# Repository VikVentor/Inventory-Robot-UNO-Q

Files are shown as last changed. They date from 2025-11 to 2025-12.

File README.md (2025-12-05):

# Smart Inventory Robot (Edge Impulse + UNO Q)
## Click to watch the video!
<a href="https://youtu.be/sMjTuYHo2wQ">
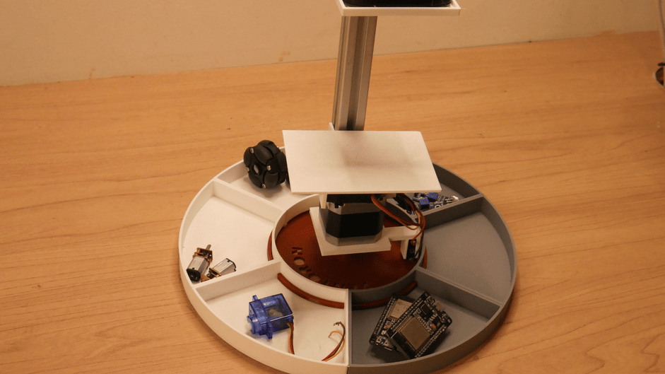
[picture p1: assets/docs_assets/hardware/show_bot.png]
  
</a>
<br>

## Introduction

This project walks you through building your own **Inventory Robot** that can automatically identify, organize, and track the components you use in your workspace. After finishing a prototype, placing every part back in the right spot can become time-consuming and difficult. This robot solves that by intelligently sorting and maintaining a clear inventory of your items.

Whether you are a beginner or a hobbyist, this guide makes it simple to understand how the robot works, how to train your machine learning model on **Edge Impulse**, and how to integrate everything with the **Arduino UNO Q**.

---

## Table of Contents

1. [Identified Problem](#1-identified-problem)  
2. [Proposed System (Solution)](#2-proposed-system-solution)  
3. [What You Will Learn](#3-what-you-will-learn)
4. [System Overview](#4-system-overview)
   - **4.1 [Hardware](#41-hardware)**  
   - **4.2 [Software](#42-software)**  
5. [System Design & Development](#5-system-design--development)
   - **5.1 [System/Hardware Design](#51-system--hardware-design)**  
   - **5.2 [Dataset Preparation](#52-dataset-preparation)**  
   - **5.3 [Training of the AI Model](#53-training-the-ai-model)**  
   - **5.4 [Optimization of AI Model](#54-optimization-of-ai-model)**  
   - **5.5 [Integration of model with UNO Q](#55-integration-of-model-with-uno-q)**  
   - **5.6 [Arduino Appilcation Development](#56-Arduino-Appilcation-Development)**  

6. [System Testing](#6-system-testing)  
7. [Summary of Challenges](#7-summary-of-challenges)  
8. [Advantages of Arduino UNO Q](#8-advantages-of-arduino-uno-q)
9. [Conclusion](#9-conclusion)

---

## 1. Identified Problem

When working on electronics projects, components often get scattered all over the workspace. After finishing your work, identifying and sorting them back into their correct locations becomes tiring. This leads to misplaced parts, wasted time searching, and reduced productivity.
#### If you are a hobbyist, your desk on an average day might look like this.
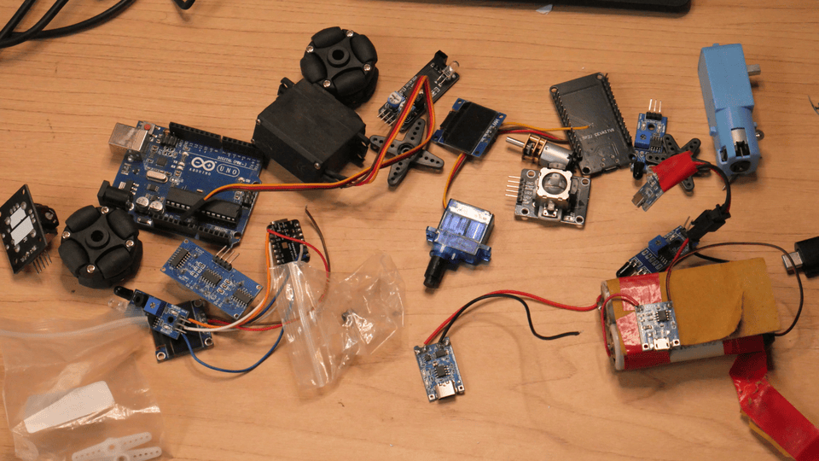
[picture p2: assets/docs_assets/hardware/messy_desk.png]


Manual sorting is repetitive and error-prone. As your component collection grows, keeping track of everything becomes even harder.

This project focuses on creating an automated system that can:

* Quickly identify items
* Count them accurately
* Sort and position them correctly
* Maintain a consistent, updated inventory

With the Arduino UNO Q and Edge Impulse, this project eliminates the repetitive steps and builds a smart, reliable solution.

---

## 2. Proposed System (Solution)

### Smart Inventory Robot with Arduino UNO Q
### After finishing a prototype, placing every part back in the right spot can become time-consuming and difficult. This robot solves that by intelligently sorting and maintaining a clear inventory of your items.

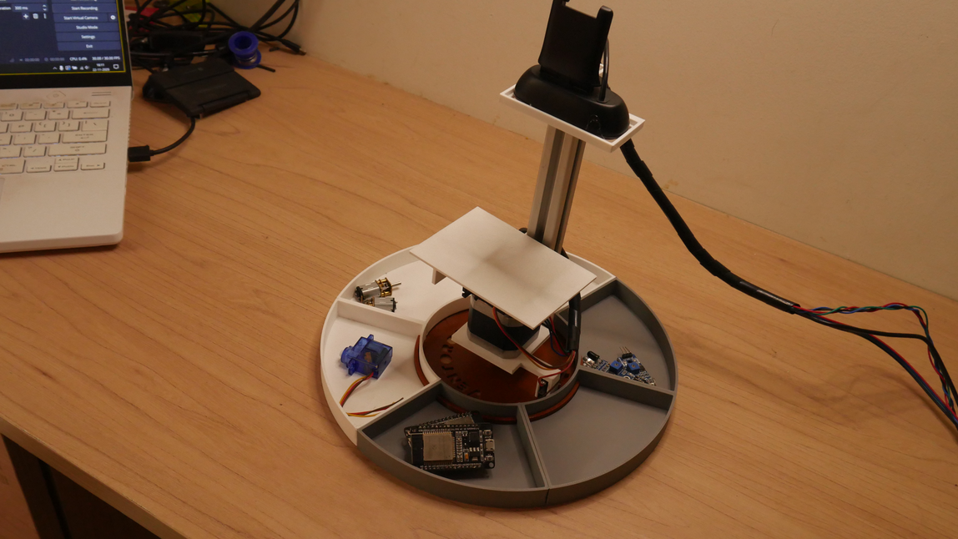
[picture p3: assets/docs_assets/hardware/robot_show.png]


### Features:
1. Automatic sorting of components into container
2. Updates total quantity of object when placed
3. You can pick any component and show it once to the camera and the total quantity will be updated.
4. find the container of a particular component

### Here's the WEB UI where you can see the detections in real time and use the find and pick feature.
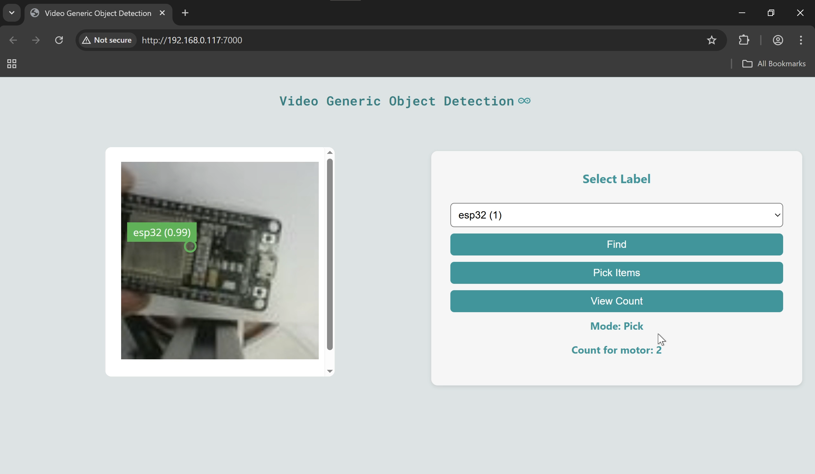
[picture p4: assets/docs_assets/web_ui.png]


---

## 3. What You Will Learn

Here are the key concepts you’ll learn while building this project:

1. How to train an ML model in **Edge Impulse**, optimize it, and integrate it into your **Arduino UNO Q** application.
2. How to utilize the UNO Q’s core ability—seamless software-to-hardware communication through the **Bridge API**.
3. How to adapt this software workflow to your own hardware setup.

**To make the process easier, I have also built the entire hardware and included all the STL files you need.**
The robot has a simple design focused on showcasing how the Arduino UNO Q and Edge Impulse can work together for smart inventory management.

---

## 4. System Overview
The Smart Inventory Robot combines autonomous navigation, vision-based item recognition, and automated sorting to manage components efficiently. The system uses a camera and machine learning model trained on Edge Impulse to classify items in real time, while the Arduino UNO Q controls the robot’s movement and mechanical sorting mechanism. Detected components are logged and organized automatically, maintaining an up-to-date inventory without manual effort. This integrated setup ensures accurate tracking, reduces human error, and streamlines workspace organization.

### 4.1 Hardware:
- An actuator (Stepper motor in this case) to navigate to the location of the respectrive object container.
- A Servo motor that drops the items once it reaches the destination container.
- A camera with adjusted focus
- Assembly of hardware (Using my design or yours)
  
### 4.2 Software:
- Arduino App Lab: to run the App that consists of your pyhton detection code and your arduino sketch to control the actuator.
- Edge Impulse Studio: This is where you will train and optimise your Edge AI model.
- Integrate your Edge AI model with your Arduino App

### Finally Software to Hardware communication is achieved using the Bridge API of UNO Q. (It will be clear in the next steps).

## 5. System Design & Development

## 5.1 System / Hardware Design

### Concept
This hardware setup is built as a **Proof of Concept** to demonstrate the Edge AI application.  
A **radial motion mechanism** is used for its simplicity, stability, and ease of construction.

### CAD / STL Files  
All CAD/STL files are provided.

### Hardware Used
- Arduino Uno Q  
- Logitech C270
- Arduino CNC Shield  
- NEMA 17 Stepper Motor (with long cable)
- A4988 Stepper Motor Driver
- Limit Switch  
- 20×20 Aluminum Extrusion (≥15 cm)  
- MG995 Servo Motor  
- 1 m wires (×4)  
- T-nuts for 20×20 extrusion  
- M3 screws

### Circuit Diagram
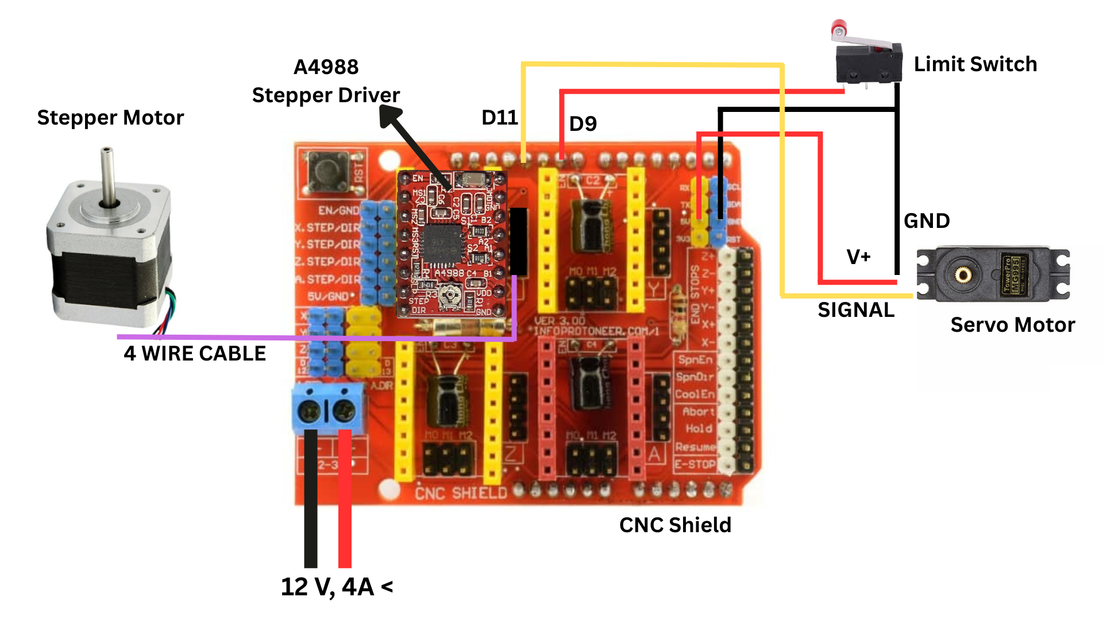
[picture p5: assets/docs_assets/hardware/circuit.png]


<br>
The long wires are for the servo motor and limit switch<br>
Among the 4 wires, 1 common wire is for the GND.
---

### a. Construct the Base  
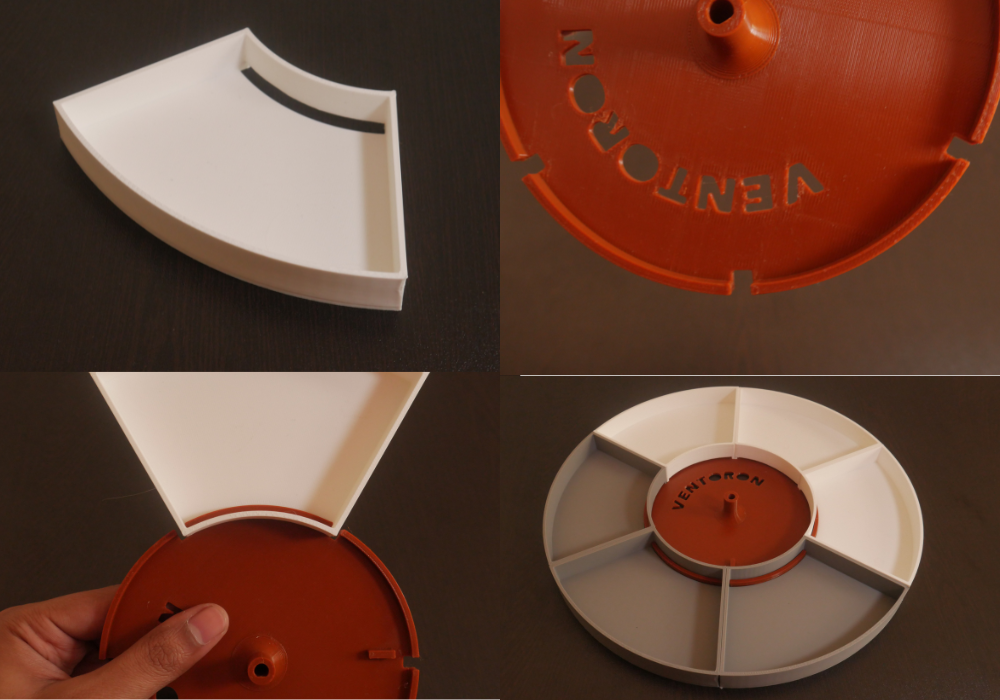
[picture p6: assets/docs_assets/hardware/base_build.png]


---

### b. Mount the Stepper Motor
Attach the aluminum extrusion to the base using a T-nut, as shown.  
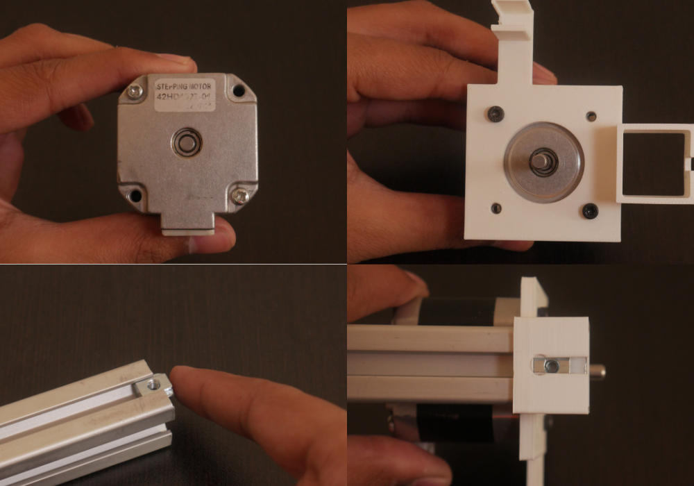
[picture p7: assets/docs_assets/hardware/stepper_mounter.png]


---

### c. Install the Limit Switch  
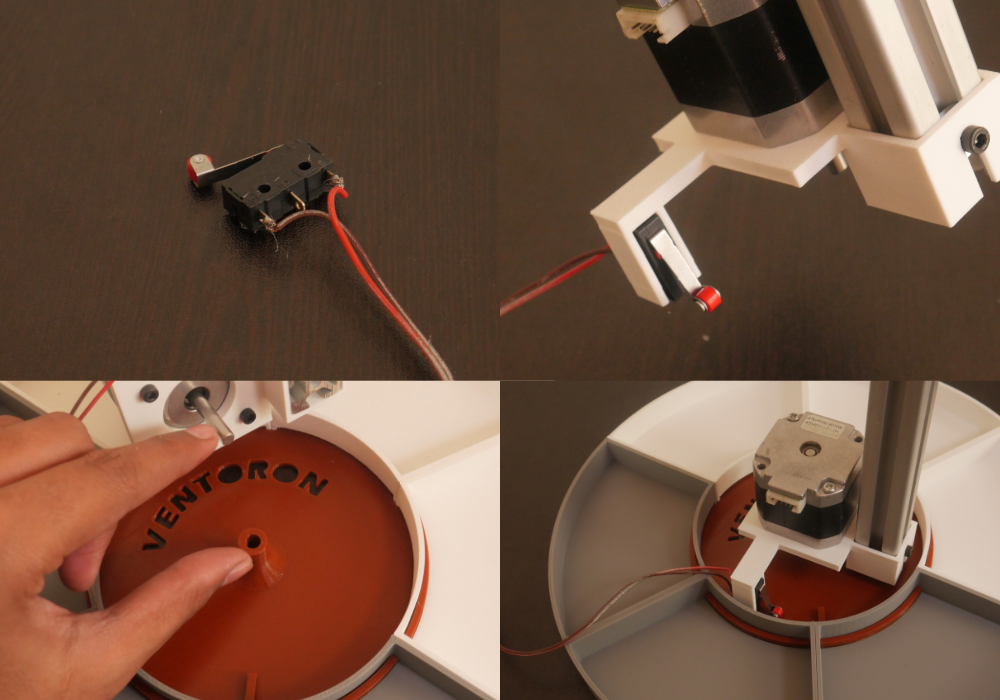
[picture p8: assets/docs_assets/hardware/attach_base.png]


---

### d. Mount the Servo and Detection Platform  
Secure the servo to the platform using the screw provided with the servo.  
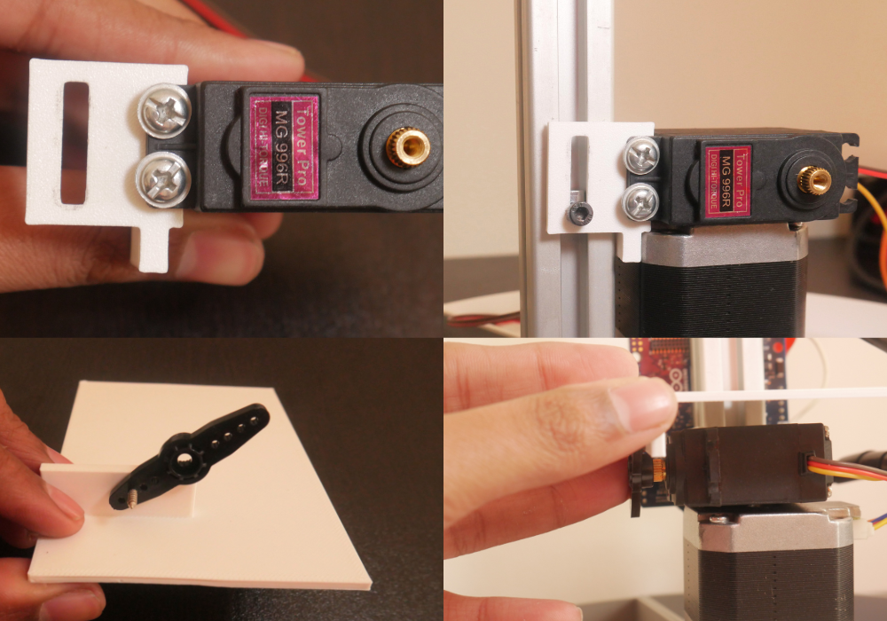
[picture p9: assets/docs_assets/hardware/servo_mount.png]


### e. Cover wires with wire sleeve
After covering the wires, you can push the sleeve into the slot of the extrusion to keep it firmly in place 
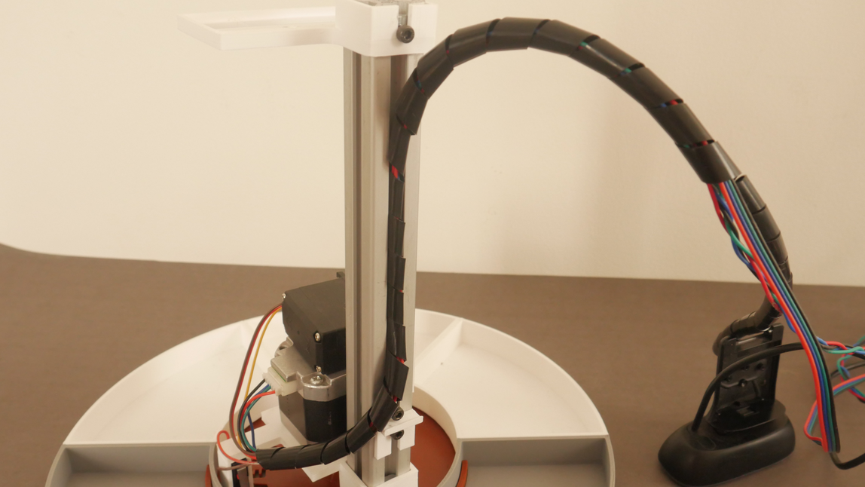
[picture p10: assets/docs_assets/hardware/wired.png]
  
<br>

---

### f. Attach and Align the Camera
Before mounting, adjust the camera focus relative to the platform.  
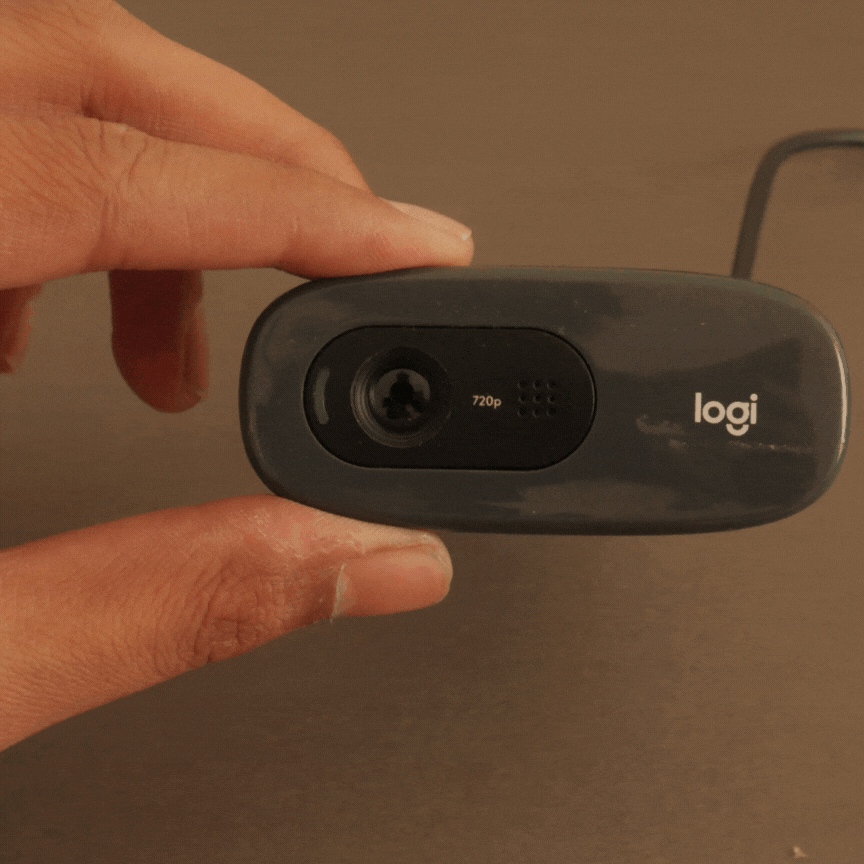
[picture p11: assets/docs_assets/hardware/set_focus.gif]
  
<br>
* Use another T nut here to secure the camera holder.
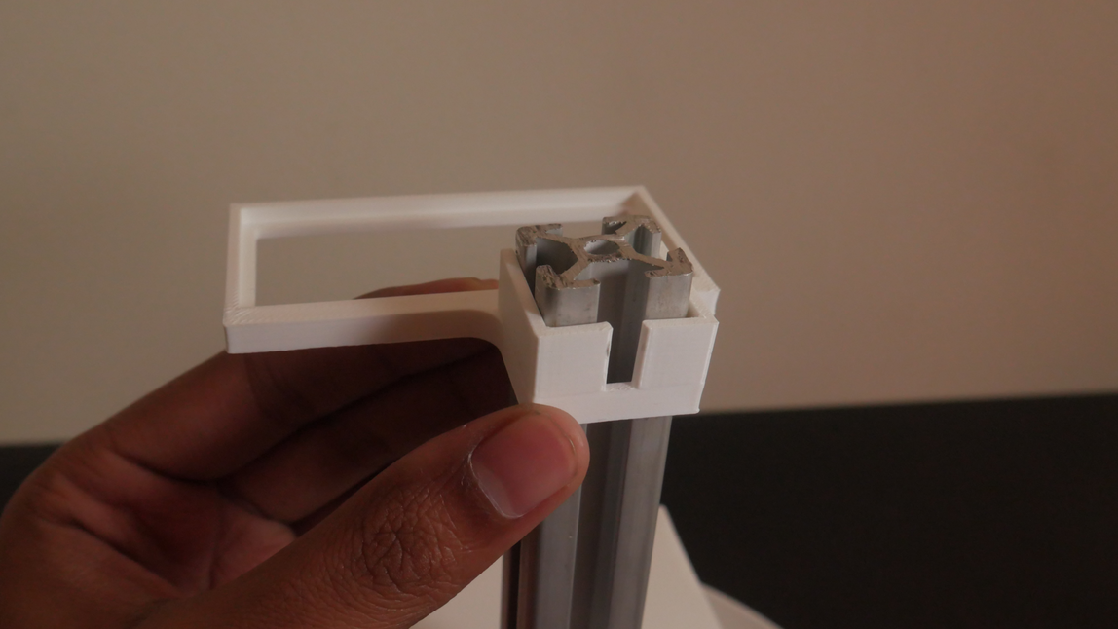
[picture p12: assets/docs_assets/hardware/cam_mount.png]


### g. Stack the CNC shield with the Arduino UNO Q board:
- Be cautious, make sure the polarity of your 12V supply is connected properly to the CNC shield
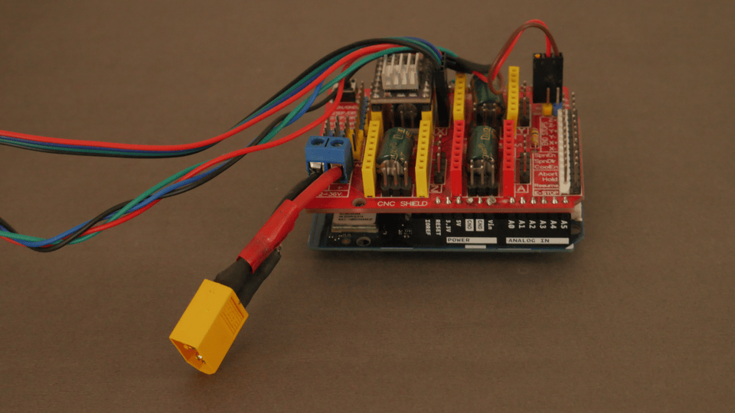
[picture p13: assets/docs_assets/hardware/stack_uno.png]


Use hot glue to fix the camera to the holder — and the hardware assembly is complete.  


---

## 5.2 Dataset Preparation

Follow these steps to prepare your dataset:

* Select 5 different objects for training.
* For each object, capture around **240 images** (200 for training, 40 for testing).

<br>
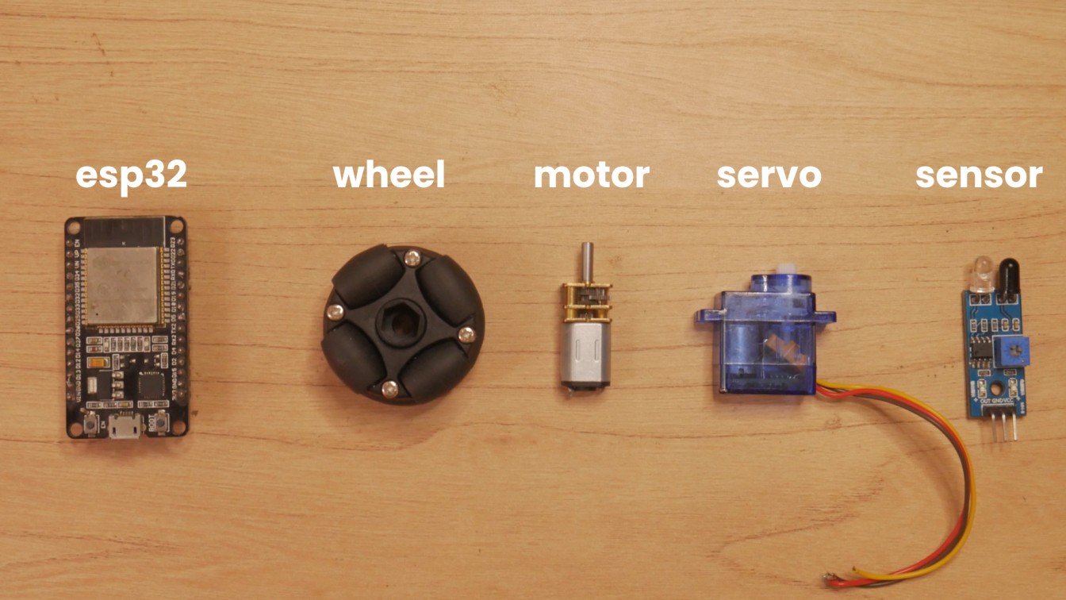
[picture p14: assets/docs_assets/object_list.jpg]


### Create your project

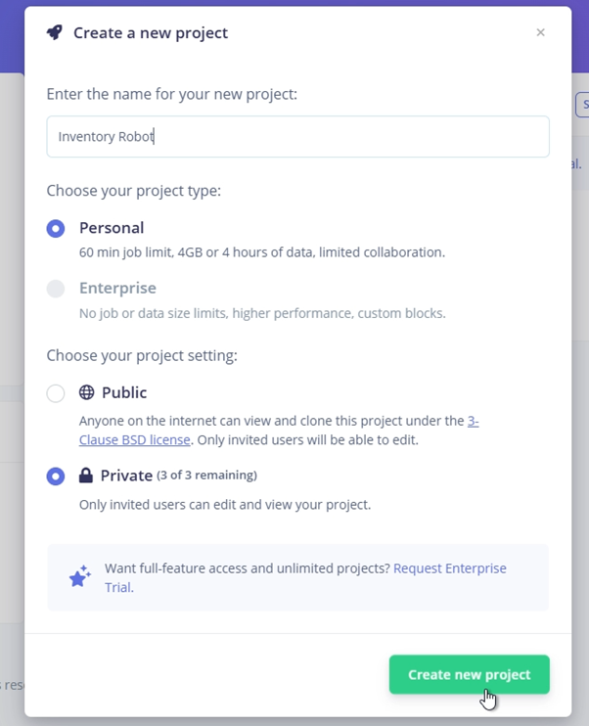
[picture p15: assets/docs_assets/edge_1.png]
  

### Collect images

Use the same camera you plan to use in the robot. Connect it to your PC and capture all the images.<br>
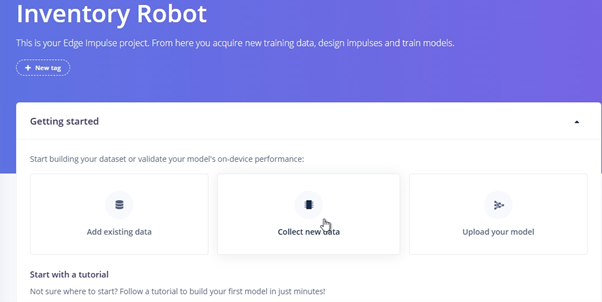
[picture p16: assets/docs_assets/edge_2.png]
  
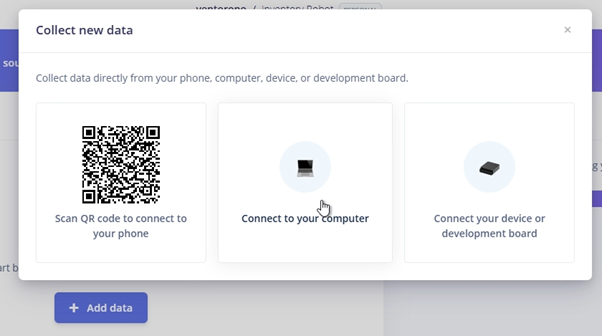
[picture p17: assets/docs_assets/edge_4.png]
  

### Select “Collecting images”

Allow camera permissions if requested.<br>
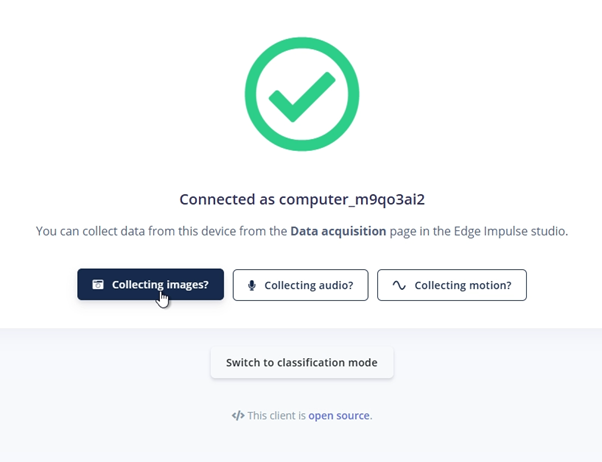
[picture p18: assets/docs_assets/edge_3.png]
  

### Capture images one by one

* Edit the label to help you identify categories later.
* Capture in different orientations and lighting conditions.
* Choose **Training** dataset first (200 images), then **Testing** dataset (40 images).

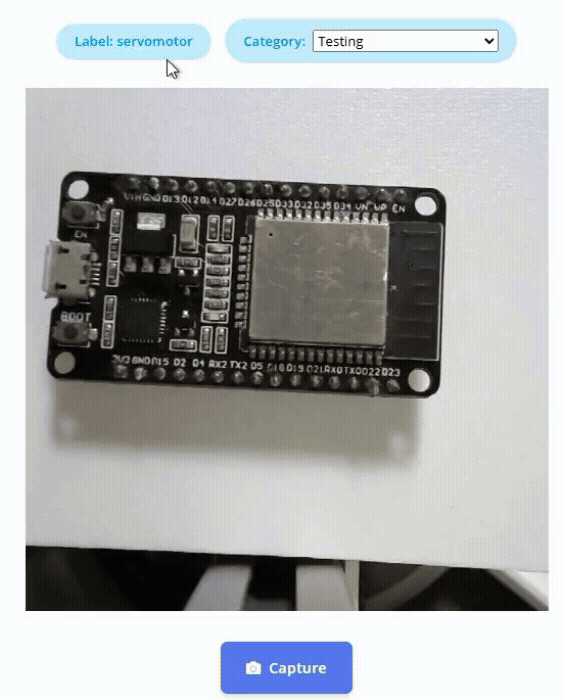
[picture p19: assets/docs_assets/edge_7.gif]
  
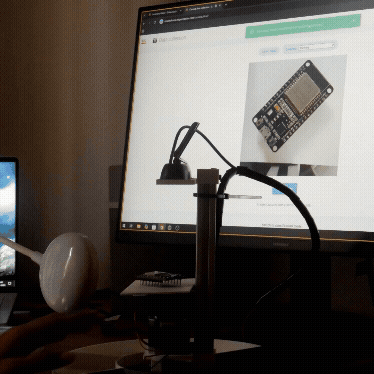
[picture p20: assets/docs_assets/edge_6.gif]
  

### Label your images with bounding boxes

* Go to **Labeling Queue**.
* Draw a bounding box around the object.
* Click **Save label** to move to the next image.
* Edge Impulse intelligently estimates bounding boxes for consecutive images.<br><br>
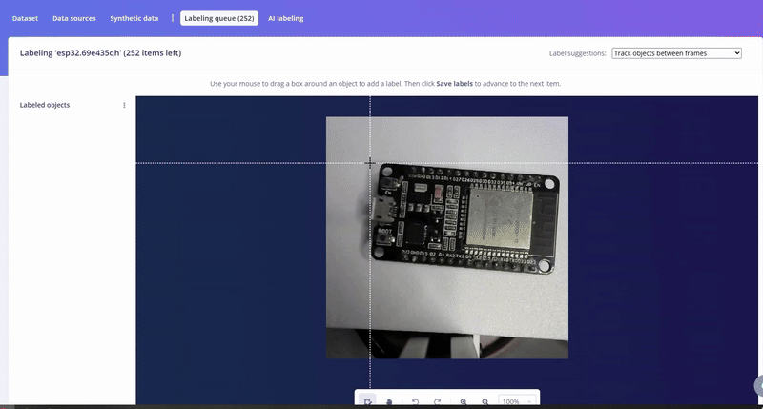
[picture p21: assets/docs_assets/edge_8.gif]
  

You can also use AI-based auto-labeling using OpenAI or Gemini API keys.

Repeat this process for all objects.

---

## 5.3 Training the AI model 

### How do you know what to choose?

Training is an experimental process—try models, adjust parameters, and iterate until you get the performance you need.

Before we dive in, here is a summary of my experiments,.

| Experiment | Model Used | Input Size | Data Augmentation | Accuracy / F1 Score | Model Size |
| --- | --- | --- | --- | --- | --- |
| **Experiment 1** | MobileNetV2 SSD FPN-Lite 320x320 | 320×320 | ❌ No | ~87% accuracy | **11 MB**  |
| **Experiment 2** | FOMO MobileNetV2 0.35 | 90×90 | ❌ No | Good F1 score but lower accuracy | **106 KB**  |
| **Experiment 3 (Final)** | **FOMO MobileNetV2 0.35** | **90×90**  | **✔️ Yes** | **High accuracy & precision** | **106 KB** |

### **Training Steps (Overview)**

1. [Create an Impulse](#creating-an-impulse)
2. [Generate Features](#generate-features)
3. [Train the Model](#train-the-model)
4. [Model Testing (Classify All)](#testing)
5. [Select Arduino UNO Q as Target](#deployment-summary)
6. [Deploy the Model (.eim File)](#integrate-with-uno-q)

---

### Creating an Impulse

* Go to **Create Impulse**.
* An impulse processes raw data into features and uses a learning block for classification.

### Experiment 1

Trying **MobileNetV2 SSD FPN-Lite 320x320** required resizing inputs to **320×320**.<br>
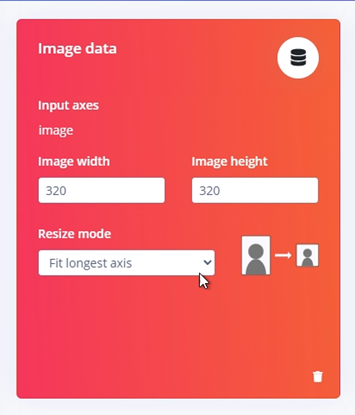
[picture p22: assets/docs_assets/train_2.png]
  

Added processing and learning blocks: <br>

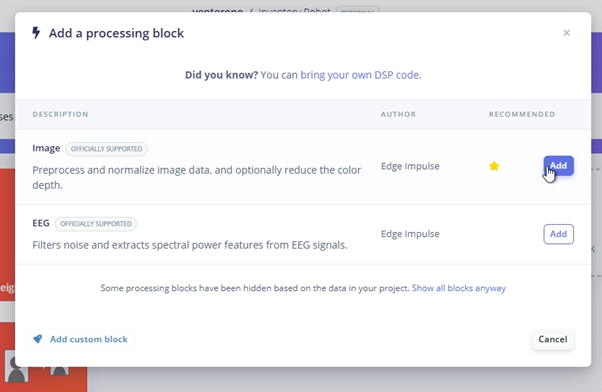
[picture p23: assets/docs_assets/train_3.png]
  
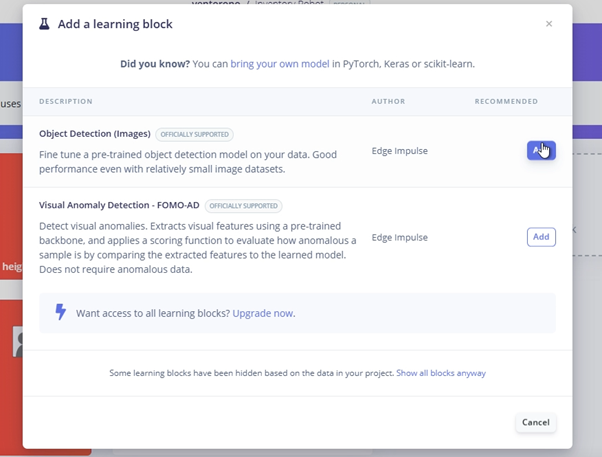
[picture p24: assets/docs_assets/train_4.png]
  

### Generate features:
- Navigate to the "Image" section to save parameters and generate feastures.<br>

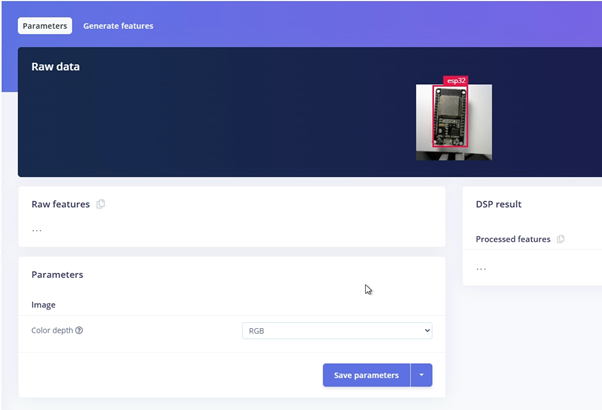
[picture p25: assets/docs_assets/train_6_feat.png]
  
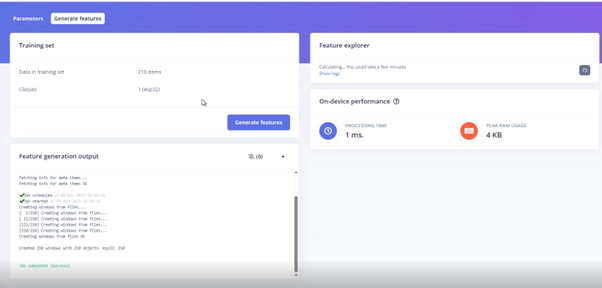
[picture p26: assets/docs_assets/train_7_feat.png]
  

### Train the model
Selected the **MobileNetV2 SSD FPN-Lite 320x320** model in the **Object Detection** section, hit **Save & Train**:<br>
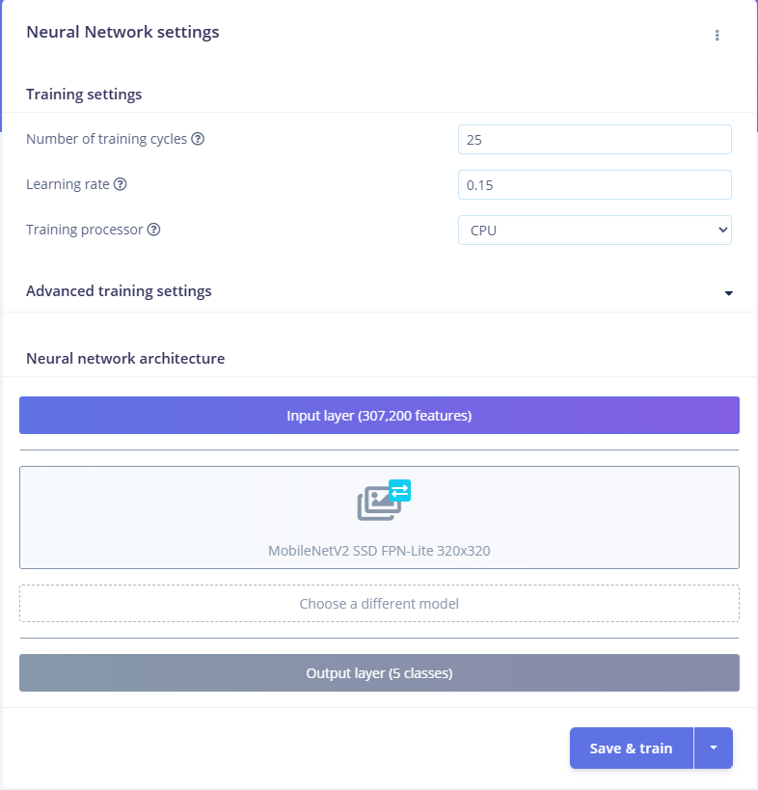
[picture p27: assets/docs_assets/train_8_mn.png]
  

Training time is limited by Edge Impulse (1 hour), so around 25–30 epochs are possible.<br>

Results:<br>
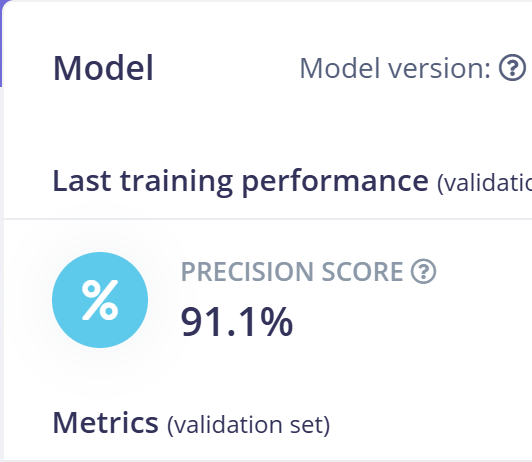
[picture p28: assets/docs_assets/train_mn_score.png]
  

### Testing

Using **Live Classification** or **Model Testing → Classify all**:<br>
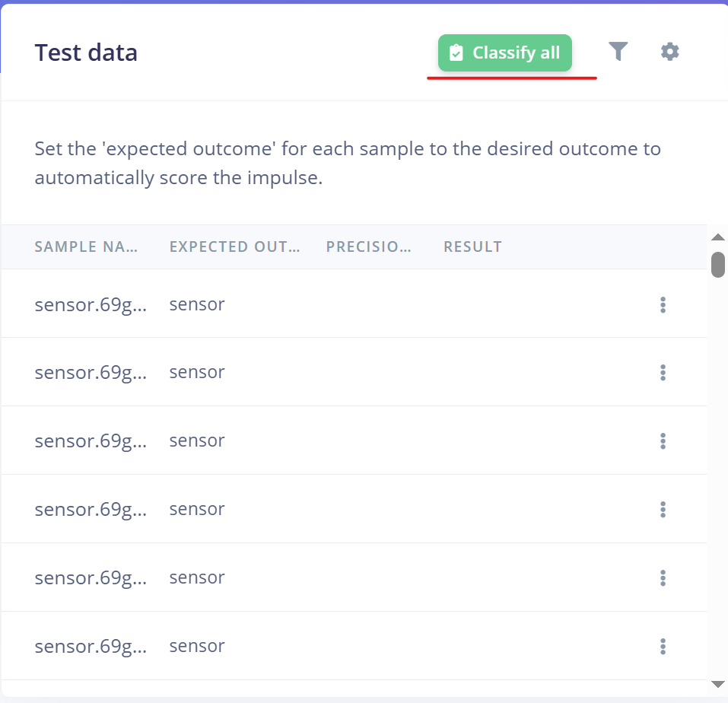
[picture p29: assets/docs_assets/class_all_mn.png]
  
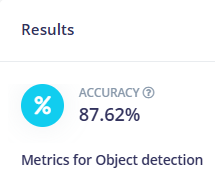
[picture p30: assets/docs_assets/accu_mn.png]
  

Accuracy was around **87%**. Good, but we can improve this.

### Deployment summary

After selecting **Arduino UNO Q** as the target:<br>

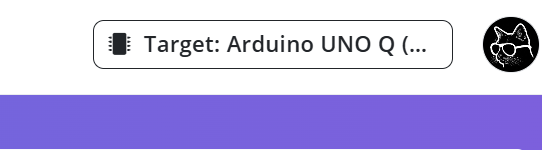
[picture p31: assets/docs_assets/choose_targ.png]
  
  <br>
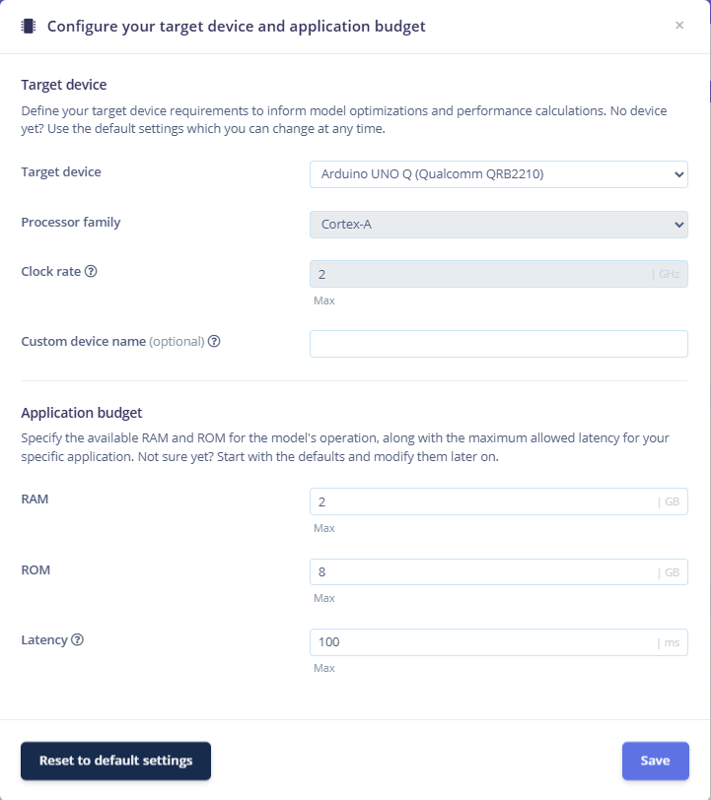
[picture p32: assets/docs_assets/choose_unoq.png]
  

On deploying:<br>

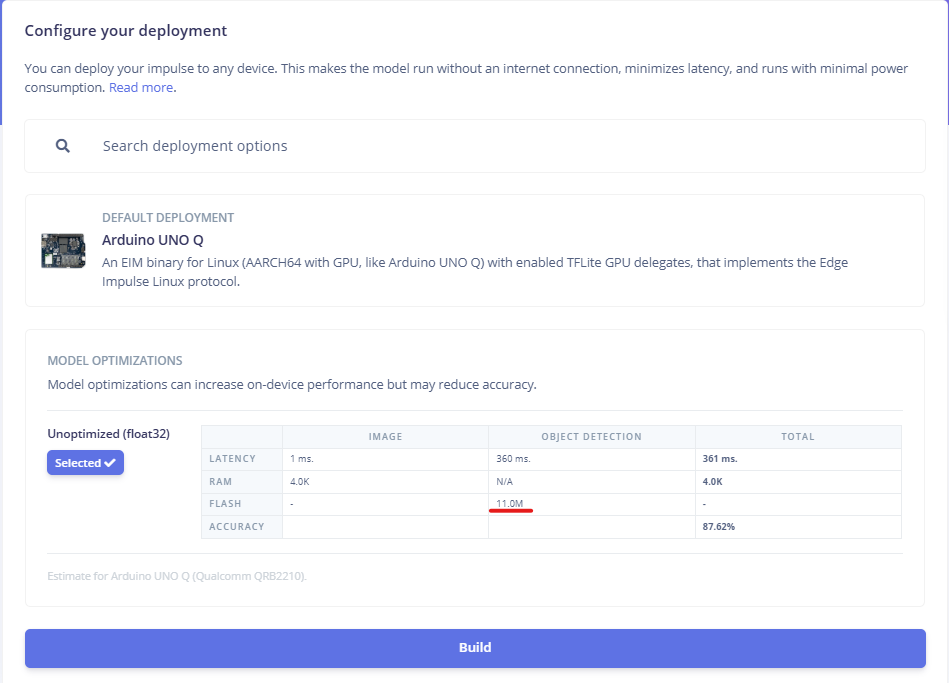
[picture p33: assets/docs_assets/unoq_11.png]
  

### Learnings from Experiment 1

* Model size was large (**11 MB**)
* Accuracy and precision can be improved
* Input size (320×320) is unnecessarily big

---

## Experiment 2

Same pipeline, but now:

* Input size changed to **90×90**
* Model switched to **FOMO MobileNetV2 0.35** (supports arbitrary image sizes)

### Impulse

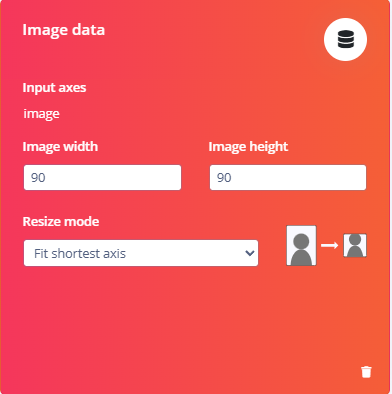
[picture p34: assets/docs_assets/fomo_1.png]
  

Training setup (no augmentation enabled):<br>

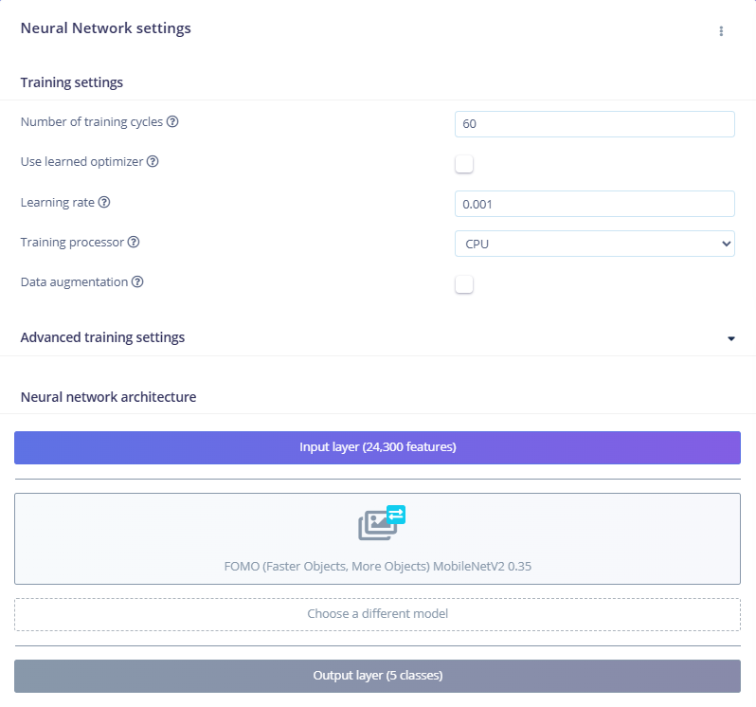
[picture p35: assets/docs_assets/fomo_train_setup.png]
  

F1 score:<br>
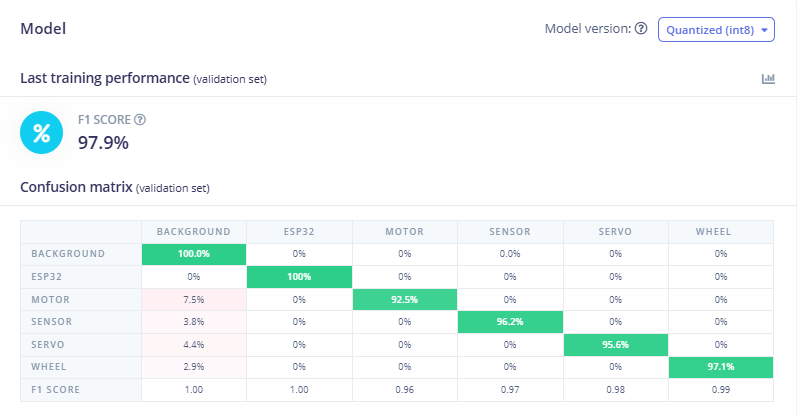
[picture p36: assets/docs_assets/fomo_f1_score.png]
  

Model accuracy:<br>

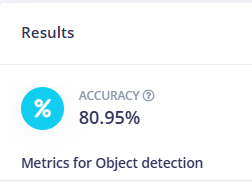
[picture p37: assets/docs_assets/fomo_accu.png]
  

---

## 5.4 Optimization of AI Model

### Experiment 3 (Final)

Everything remained the same except enabling **Data Augmentation**:<br>

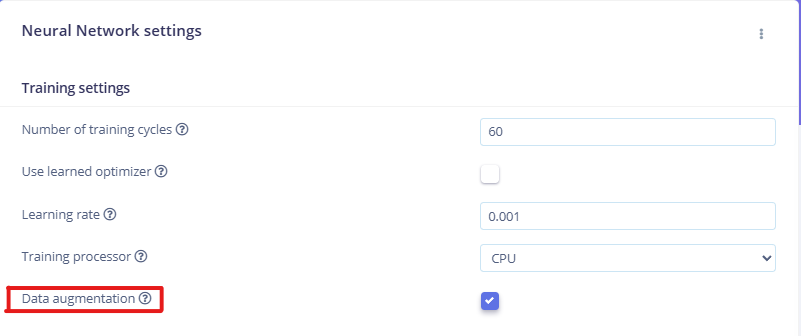
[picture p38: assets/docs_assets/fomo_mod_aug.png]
  

Precision:<br>

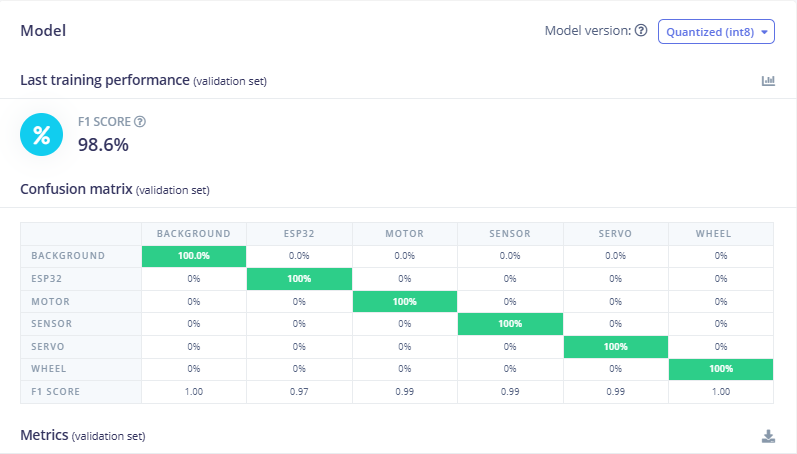
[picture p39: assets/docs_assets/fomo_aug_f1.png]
  

Accuracy:<br>

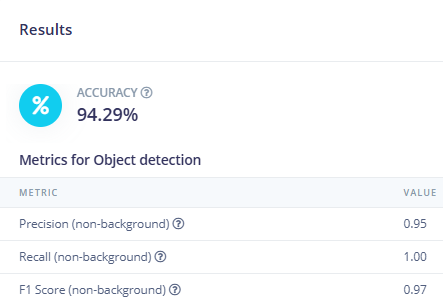
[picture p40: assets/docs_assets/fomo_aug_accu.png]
  

### Why this worked better

* Data augmentation prevents overfitting
* Model becomes more robust to variations
* Model size reduced from **11 MB → 106 KB**
* Training speed significantly improved

### Summary of Experiments

---

If you'd like, I can also add a short one-line takeaway below the table.

---

## 5.5 Integration of model with UNO Q

### Setup the Arduino UNO Q as a Single Board Computer:
[Arduino Uno Q Single-Board Computer Set](https://docs.arduino.cc/tutorials/uno-q/single-board-computer/)

If you face issues with App Lab on your board, consider reflashing it with a new image:
<br>
[Flash a new Image](https://docs.arduino.cc/tutorials/uno-q/update-image/)

### Once your UNO Q is setup and ready, login to your **Edge Impulse Account** in UNO Q
You’ll need the **.eim** file from Edge Impulse.
Go to **Deployment → Build**
The `.eim` file downloads automatically once the build completes.<br>

  

### Adding the app
You can access folders and files on UNO Q using **Thunar**, which is like file explorer on Windows.
#### Download this repository on your UNO Q, and store the Unzipped Folder inside the **Arduino Apps** Folder.
  
  

### Adding the .eim model file
* Enable "Show hidden Files" in Thunar
* Navigate to **.arduino-bricks → ei-models** and paste the downloaded .eim file here



### The app.yaml file.
* Navigate to **Arduino App → Inventory-Robot-UNO-Q → app.yaml**

```yaml
name: Inventory-Robot-UNO-Q
description: This example showcases object detection within a live feed from a USB camera.
ports: []
bricks:
- arduino:video_object_detection: {variables: {
      EI_OBJ_DETECTION_MODEL: /home/arduino/.arduino-bricks/ei-models/inventory-robot-linux-aarch64-gpu-v10.eim
    }}
- arduino:web_ui: {}
icon: 📽️

```
* Replace the .eim file name with your downloaded file name
* You can replace the **name** with your own app name, if needed.

---

## 5.6 Arduino Appilcation Development

File Structure:
<br>

<br>
File description:
1. Accelstepper Library
2. Servo Library
3. Python Code
4. Arduino Sketch

You can add libraries just like how you do in Arduino IDE, by pressing the button next to "Library"

Under assets, you can view the **index.html** and **app.js** which you can modify for your use case too:<br>


### The label_map.json is an important file:
This is where you can add
- A new object
- Its position
- Its total count
<br>
Here's an example of its representation in the file:

| object | position | total count |
|---|---|---|
| esp32  | 2 | 15 |

### I have initialized all the count values as 0 because the robot will update its count automatically as it places them in their respective positions

```json
{
  "esp32": [2,0],
  "servo": [3,0],
  "motor": [3,0],
  "wheel": [4,0],
  "sensor": [5,0]
}
```

## Interaction Between Python and Arduino

### **Python Logic**

```python
def send_detections_to_ui(detections: dict):
    global paused, pick_mode

    if paused:
        return

    now = time.time()

    for key, value in detections.items():
        conf = value.get("confidence", 0)

        if conf * 100 < 85 or key not in label_map:
            continue
        if now - last_detection_time.get(key, 0) < DETECTION_COOLDOWN:
            continue

        last_detection_time[key] = now

        if pick_mode:
            label_map[key][1] = max(0, label_map[key][1] - 1)
        else:
            label_map[key][1] += 1
            Bridge.notify("stepper", label_map[key][0])   # send position to UNO Q
            paused = True

        save_label_map()
        ui.send_message("count_update", {"label": key, "count": label_map[key][1]})

detection_stream.on_detect_all(send_detections_to_ui)
```

**Summary:**

* Only detections above **85% confidence** are considered.
* For each valid detection, Python sends the object’s **position index** to the UNO Q using `Bridge.notify("stepper", position)`.
* Python enters a **paused** state until the microcontroller confirms that the item has been placed.

---

### **Arduino Logic**

* Below is a minimal skeleton showing how the UNO Q receives commands and sends back acknowledgements:
* You can use this code structure for your own project.

```cpp
#include <Arduino_RouterBridge.h>

long positions[6] = {0, 33, 66, 99, 132, 165};
// my stepper motor takes 200steps for one revolution, so these values are the respective positions for the 6 containers

void movePos(int n) {
    // your hardware logic here (stepper, servo, etc.)

    int var = 0;
    Bridge.notify("ack", var);   // send ack back to Python
}

void setup() {
    Bridge.begin();
    Monitor.begin(115200);
    // initialization logic
}

void loop() {
    Bridge.provide("stepper", movePos);  // listen for "stepper" events from Python
}
```

**Summary:**

* `Bridge.provide("stepper", movePos)` waits for Python to send a position.
* The received integer `n` tells the motor which container to move to.
* Once the object is dropped, Arduino sends back `Bridge.notify("ack", 0)`.

---

### **Python Resumes Detection After Ack**

```python
def resume(val: int):
    global paused
    if val == 0:
        paused = False

Bridge.provide("ack", resume)
```

**Summary:**

* Arduino’s acknowledgment (`ack = 0`) triggers the Python code to **unpause**.
* The detection loop continues only after the robot finishes placing the object.
* Other parts of the code handle the features of the UI

---

## 6. System Testing
Before testing it yourself, you may refer this video on how the System should work:
Watch the video (https://youtu.be/sMjTuYHo2wQ)
### Add or remove objects:
- If you want to add or remove items, add it in the format as shown in the label_map.json file.
```json
{
  "esp32": [2,0],
  "servo": [3,0],
  "motor": [3,0],
  "wheel": [4,0],
  "sensor": [5,0]
}
```
| object | position | total count |
|---|---|---|
| esp32  | 2 | 15 |

### The main task, sorting the component.
### Simply place it on the detection platform, the camera identifies the object and places it automatically

### Here's the WEB UI where you can see the detections in real time and use the find and pick feature.


### Enter Pick Mode: 
- Click on pick, take the component you want to and place it for approximately a second on the platform.
- The total quantity is automatically updated
- To exit Pick Mode, click the pick button again and it returns to normal Mode.

### Count
- Scroll through the dropdown to select the object you want, it shows the total quantity present in the container.

### Find
- If your system has more than 6 containers , like maybe 20, Finding the container of you object is difficult.
- Simply scroll through and select the object you want. Press "Find", the robot will move to point that container.

### These features work as intended in my configuration. 
### If you are building your own, make sure that your actuator moves it to the correct containers.
---
## 7. Summary of Challenges
1. Getting real-time detection to work accurately was tough because many components look very similar.
2. Optimizing the Edge Impulse model to run smoothly on limited hardware required a lot of tweaking.
3. Keeping the inventory count correct without duplicate or missed detections was challenging.
4. Making the robot sort and place items properly needed precise motor tuning.
5. Syncing everything live with the web UI and keeping it responsive took effort.
6. Combining the camera, ML model, robot control, and UI into one smooth system required plenty of debugging.

## 8. Advantages of Arduino UNO Q
1. Dual-processor design lets you run real-time control and high-level Linux tasks together.
2. Supports Debian Linux, enabling complex apps, AI models, and web services.
3. Built-in Wi-Fi + Bluetooth for easy IoT and network integration.
4. Compatible with classic Arduino UNO shields and pin layout.
5. Has more memory and storage (eMMC) for data handling and AI workloads.
6. Reduces system complexity by replacing separate SBC + MCU setups with a single board.

## 9. Conclusion

The Smart Inventory Robot proves how edge AI can simplify real-world automation. 
**Edge Impulse** made model training and deployment straightforward, letting the system achieve accurate component recognition without complex ML development. With the **Arduino UNO Q**, both real-time motor control and on-board AI processing run on the same device, removing the need for multiple boards and reducing system complexity. Together, they enabled a compact, responsive, and efficient solution for automated inventory management.

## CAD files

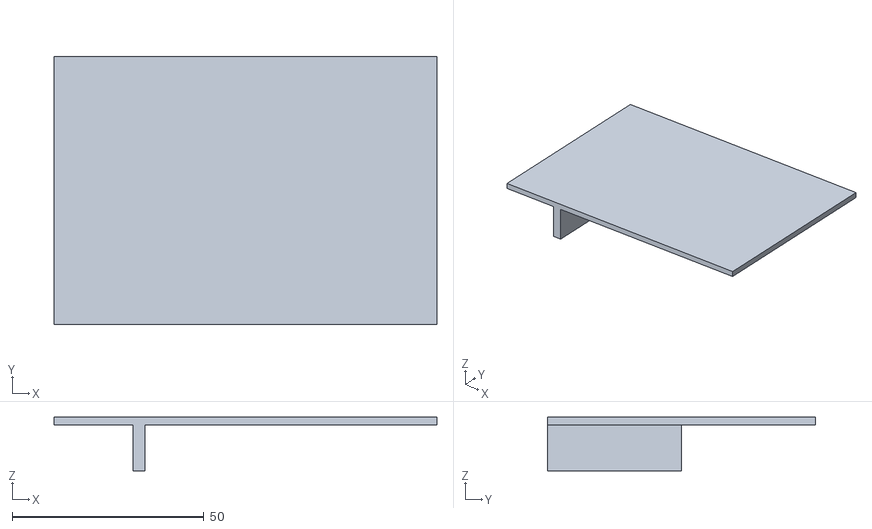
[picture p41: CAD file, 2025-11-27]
stl_files/detect_platform.stl
100.0 x 70.0 x 14.0

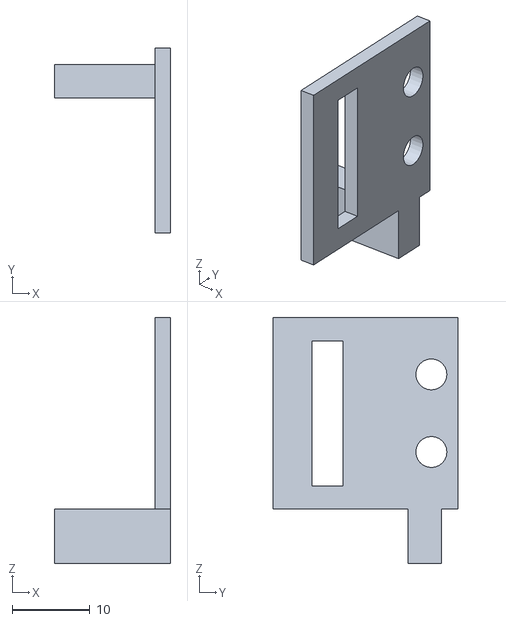
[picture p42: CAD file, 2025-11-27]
stl_files/servo_mount.stl
15.0 x 23.8 x 31.7

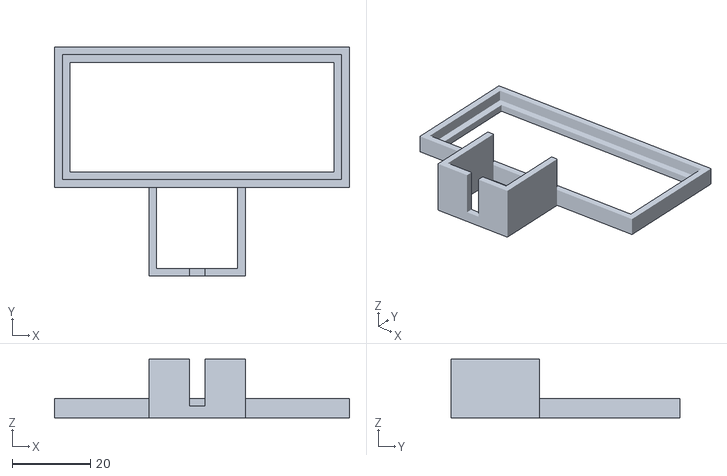
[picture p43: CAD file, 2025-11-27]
stl_files/cam_holder.stl
75.5 x 58.7 x 15.0

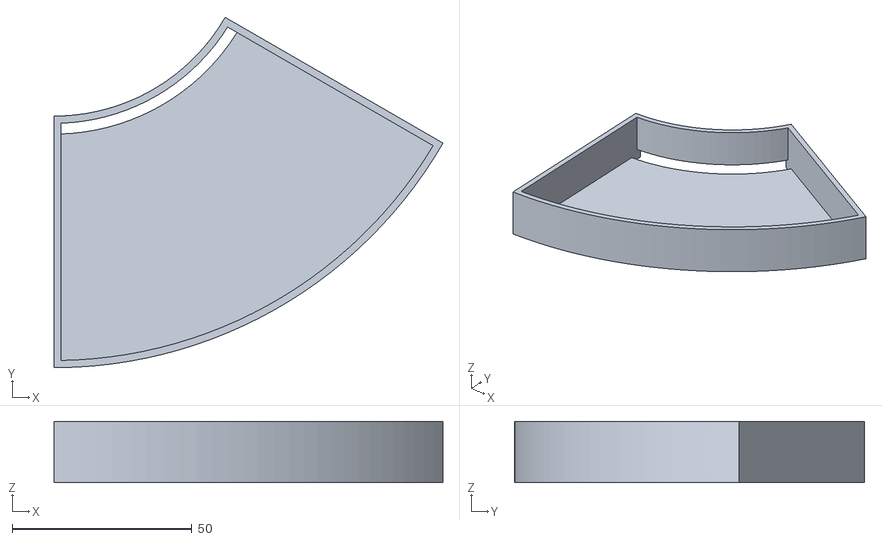
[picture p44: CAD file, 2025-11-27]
stl_files/container.stl
108.3 x 97.5 x 17.0

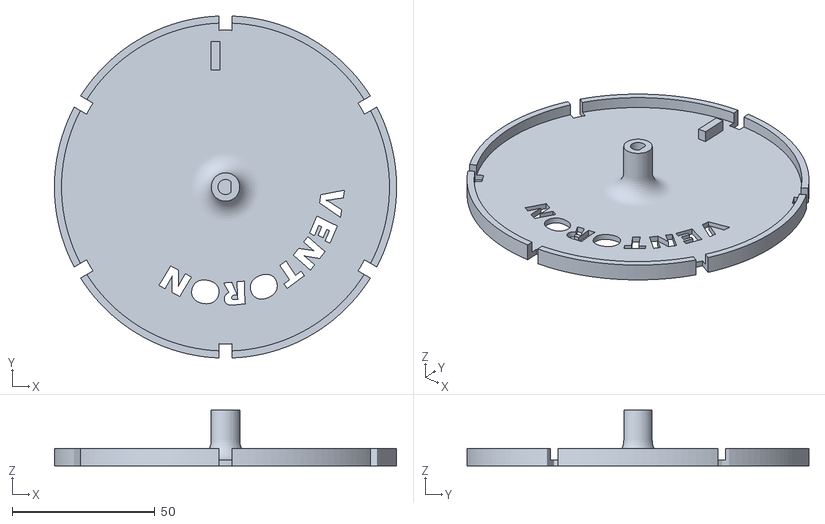
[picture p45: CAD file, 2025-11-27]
stl_files/base.stl
120.0 x 119.9 x 19.5

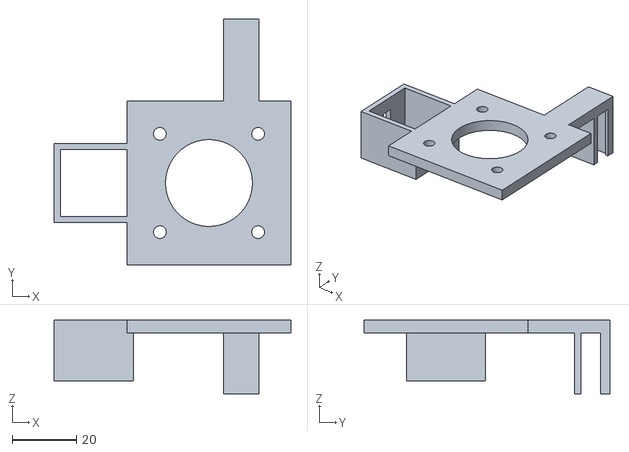
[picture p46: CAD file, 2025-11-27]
stl_files/stepper_mount.stl
73.7 x 76.5 x 23.0

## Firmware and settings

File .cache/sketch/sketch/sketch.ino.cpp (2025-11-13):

#include <Arduino.h>
#line 1 "/home/arduino/ArduinoApps/objdet_copy/sketch/sketch.ino"
#include <Arduino_RouterBridge.h>
#include <AccelStepper.h>

#define STEP_PIN 2
#define DIR_PIN 5
#define ENABLE_PIN 8
#define LIMIT_PIN 9
#define SERVO_PIN 11

AccelStepper stepper(AccelStepper::DRIVER, STEP_PIN, DIR_PIN);

bool homed = false;
long positions[6] = {0, 33, 66, 99, 132, 165};

#line 15 "/home/arduino/ArduinoApps/objdet_copy/sketch/sketch.ino"
void pwmServo(int deg);
#line 23 "/home/arduino/ArduinoApps/objdet_copy/sketch/sketch.ino"
void moveServo(int deg);
#line 28 "/home/arduino/ArduinoApps/objdet_copy/sketch/sketch.ino"
void servoDrop();
#line 34 "/home/arduino/ArduinoApps/objdet_copy/sketch/sketch.ino"
void movePos(int n);
#line 57 "/home/arduino/ArduinoApps/objdet_copy/sketch/sketch.ino"
void setup();
#line 83 "/home/arduino/ArduinoApps/objdet_copy/sketch/sketch.ino"
void loop();
#line 15 "/home/arduino/ArduinoApps/objdet_copy/sketch/sketch.ino"
void pwmServo(int deg) {
    int pulse = map(deg, 0, 180, 1000, 2000);
    digitalWrite(SERVO_PIN, HIGH);
    delayMicroseconds(pulse);
    digitalWrite(SERVO_PIN, LOW);
    delayMicroseconds(20000 - pulse);
}

void moveServo(int deg) {
    for (int i = 0; i < 50; i++)
        pwmServo(deg);
}

void servoDrop() {
    moveServo(35);
    delay(2000);
    moveServo(75);
}

void movePos(int n) {
    if (n < 1 || n > 6) return;
    delay(2000);

    long target = positions[n - 1];
    Monitor.println("moving stepper");
    stepper.moveTo(target);

    while (stepper.distanceToGo() != 0)
        stepper.run();

    servoDrop();

    int var = 0;
    Monitor.println("sending ack");

    stepper.moveTo(10);
    while (stepper.distanceToGo() != 0)
        stepper.run();

    Bridge.notify("ack", var);
}

void setup() {
    pinMode(ENABLE_PIN, OUTPUT);
    digitalWrite(ENABLE_PIN, LOW);
    pinMode(LIMIT_PIN, INPUT_PULLUP);
    pinMode(SERVO_PIN, OUTPUT);

    Bridge.begin();
    Monitor.begin(115200);

    stepper.setMaxSpeed(1000);
    stepper.setAcceleration(1000);

    while (!homed) {
        if (digitalRead(LIMIT_PIN) == HIGH) {
            stepper.stop();
            stepper.setCurrentPosition(0);
            homed = true;
        } else {
            stepper.setSpeed(-50);
            stepper.runSpeed();
        }
    }

    servoDrop();
}

void loop() {
    Bridge.provide("stepper", movePos);
}
